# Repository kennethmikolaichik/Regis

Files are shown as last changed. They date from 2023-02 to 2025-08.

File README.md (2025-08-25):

# Regis Quadruped Robot
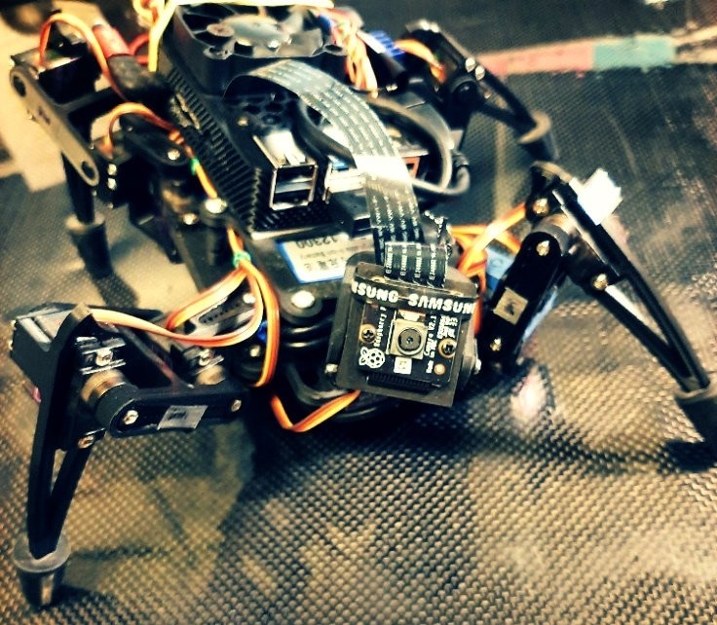
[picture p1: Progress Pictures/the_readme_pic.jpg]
Regis Looking Cool


https://github.com/user-attachments/assets/0da9238e-a415-42d3-97d8-b65ffef475de

- - - - - - - - - - - - - - - - - - - - - - - - - - - - - - - - - - - - - 
## Inspiration and General Description
- - - - - - - - - - - - - - - - - - - - - - - - - - - - - - - - - - - - - 
This project started out as a desire to bring to life a teachable basic robot.

The robot is a basic mobile quadrupedal chassis, power source, and two axis camera head designed loosely around a spider. Although battery life is limited due to the power requirements of the Raspberry Pi and SSD, it can easily run plugged in on a tabletop.

Long live Regis!

- - - - - - - - - - - - - - - - - - - - - - - - - - - - - - - - - - - - - 
## Technical Specifications
- - - - - - - - - - - - - - - - - - - - - - - - - - - - - - - - - - - - - 
Computer: Raspberry pi 4B 2GB Ram

Camera: Raspberry Pi Cam Version 2.1

Fan: 50 x 50 x 10mm (5V)

Hard Drive: Kingston mSATA SSD (recommend 128GB or greater)

HD Converter: Eluteng mSATA to usb3.0 adapter

Battery: DC 12300 - DC12V Rechargeable 3000mAh lithium-ion Battery

Servos: 14 x MG90S

Power Converter: UCTRONICS DC 6V-24V to DC 5V 5A Buck Converter Module, 9-36V Step Down to USB 5V Transformer Dual Output Voltage Regulator Board

Screws:

M2.5 for MG90S mounting

M4 for structure

- - - - - - - - - - - - - - - - - - - - - - - - - - - - - - - - - - - - - 
## Chassis
- - - - - - - - - - - - - - - - - - - - - - - - - - - - - - - - - - - - - 

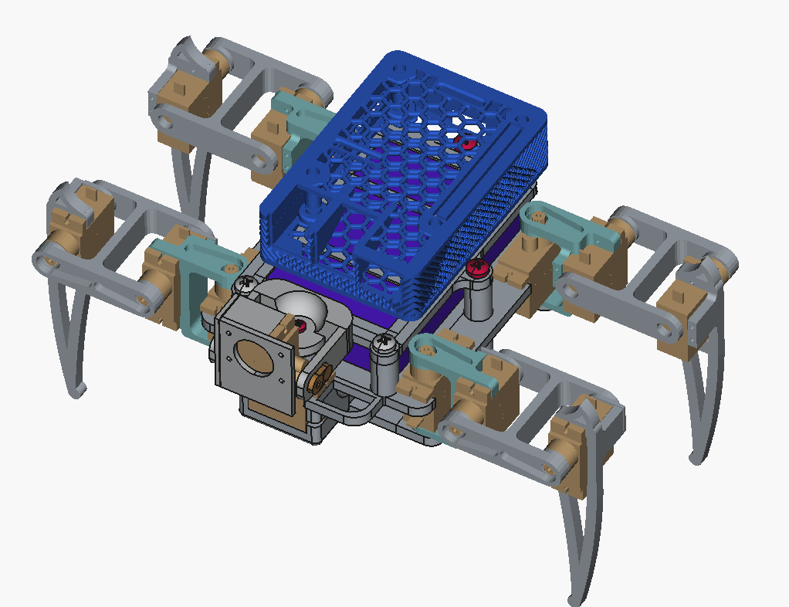
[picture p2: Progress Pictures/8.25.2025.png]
Chassis Cad Model


Use Regis > CAD & .stl files > Version 0.0
All structural pieces are 3D printed using PLA or ABS filament. Recommend high percentage to solid infill.

CAD files have been created in FreeCAD Version 0.19 - (.FCStd) filetype. 

Freecad: https://www.freecad.org/ 

The robots "shoes" have been constructed from rubber stoppers from the hardware store. They are necessary for any sort of traction on smooth surfaces. Purchase 1/2 inch stoppers and drill halfway through with a 7/64" or 1/4" drill bit. Clean out the holes and slide on the ends of the legs.

- - - - - - - - - - - - - - - - - - - - - - - - - - - - - - - - - - - - - 
## Power Distribution Board
- - - - - - - - - - - - - - - - - - - - - - - - - - - - - - - - - - - - - 
The power distribution board for the 14 motors is a necessity. For this, purchase a header set and a small piece of protoboard (~5 inches). The protoboard can be easily cut with a box cutter. Score one side and snap against a hard, clean edged surface. solder the positive, negative, and signal traces like so:

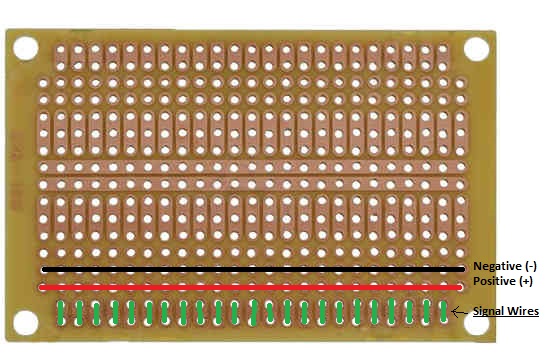
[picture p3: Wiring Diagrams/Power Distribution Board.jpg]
PDP Pic


\"- - - - - - - - - - - - - - -"•  ← negative lead from power converter\
\" + + + + + + + + + +"•  ← positive lead from power converter\
s1 s2 s3 s4 s5 s6 ...... s14   ← signal wire IN from motor  
s1 s2 s3 s4 s5 s6 ...... s14   ← signal wire OUT to Pi

Solder all positive pins together. Solder all negative pins together. Solder the pairs of signal pins together.
This way the 3-pin connector for each leg can be bundled together and a motor easily removed if needed. You may want to create some extra slots if you plan on connecting more motors or other 5V equipment. See pictures.

- - - - - - - - - - - - - - - - - - - - - - - - - - - - - - - - - - - - - 
## Method of Assembly
- - - - - - - - - - - - - - - - - - - - - - - - - - - - - - - - - - - - - 
The legs for this project are assembled with the screws that come with the MG90 Servos. They are 2.5mm. The battery case is assembled with M4 machine screws. The raspberry pi is installed in the case and held to the upper surface of the battery/case with double sided tape. The fan is attached to the upper portion of the raspberry pi case with some oversized wood screws. The SSD is attached with double sided tape, electrical tape is used to shield the IC's. Twist ties are employed throughout the robot for wire control and routing.

For wiring: You will need to 1) Plug the battery into the power converter. 2) Wire the power distribution board to the power converter. 3) Route and plug in all motors to the power distribution board. 4) Connect all signal wires to their proper Raspberry Pi GPIO pin. 5) Connect the fan to the power converter output (this way it will always be on when the battery is on) 6) plug in the SSD/mSATA to USB adapter and then into pi. The camera requires a ribbon cable.

See Diagrams

- - - - - - - - - - - - - - - - - - - - - - - - - - - - - - - - - - - - - 
## Interface
- - - - - - - - - - - - - - - - - - - - - - - - - - - - - - - - - - - - - 

#### Download the Pi Image here: https://downloads.raspberrypi.org/raspios_full_armhf/images/raspios_full_armhf-2023-05-03/2023-05-03-raspios-bullseye-armhf-full.img.xz

For advanced users you may want to set up SSH to dial into your spider.
Otherwise connect a monitor (or tv) to the micro HDMI port.
Connect a mouse and keyboard to the Raspberry Pi USB ports. I highly recommend a wireless keyboard and mouse combo. Currently running the official raspberry pi GUI, 32 bit for reliability reasons.

You will now need to install some packages and programs. Make sure to use Python 3 as some of the camera software will not work correctly with Python 2 and below. From the terminal/command line, install the following packages. 

	sudo apt-get install -y \
	  python3 python3-pip python3-numpy python3-pygame python3-pigpio \
	  pigpio espeak-ng espeak-ng-data libespeak-ng1 build-essential python3-dev

	python3 -m pip install playsound pyttsx3 --break-system-packages

This is necessary in order for the python packages to be imported sucessfully when the Robot control script is run in the next section.

You may want to install some computer vision software. (not necessary)

To install openCV, https://opencv.org/get-started/
    
    pip3 install opencv-python

Also follow this video and documentation to install Tensorflow Lite, https://www.youtube.com/watch?v=Lyh84KMqUPI

https://www.tensorflow.org/lite/guide/python

    python3 -m pip install tflite-runtime

A Note about Software:
The servo PWM timing is written with the aid of the PiGPIO library:
https://abyz.me.uk/rpi/pigpio/

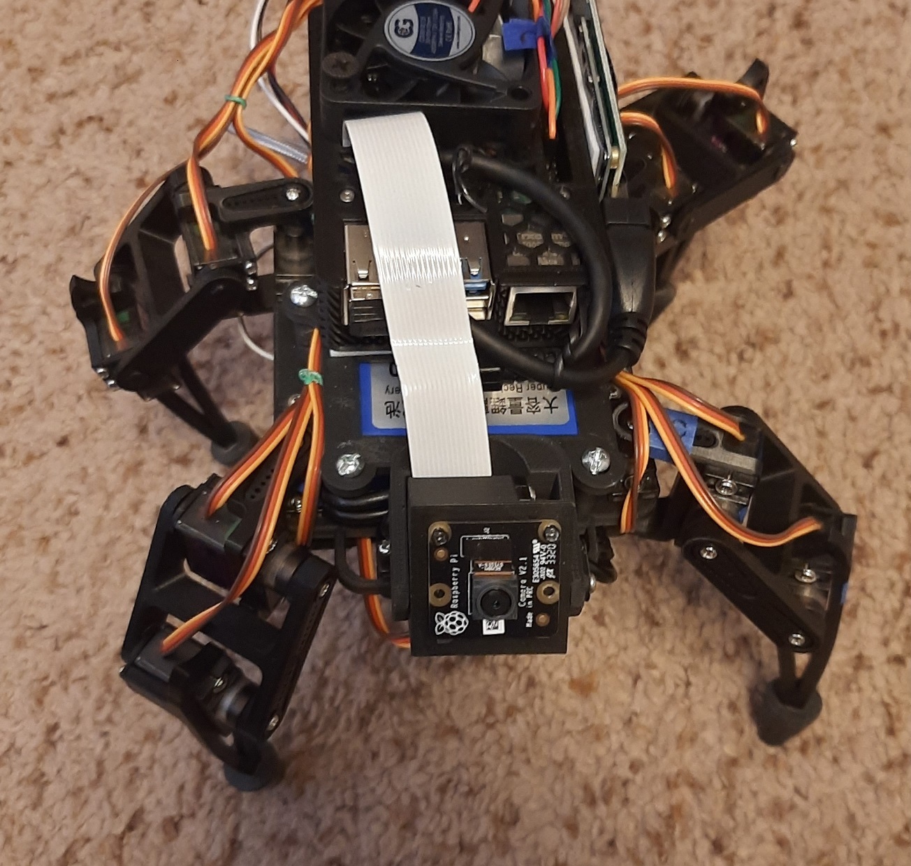
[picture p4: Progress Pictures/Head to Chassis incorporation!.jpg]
Look Up

- - - - - - - - - - - - - - - - - - - - - - - - - - - - - - - - - - - - - 
## Using Your Spider
- - - - - - - - - - - - - - - - - - - - - - - - - - - - - - - - - - - - - 
Now that your very own 'Regis' robot is up and running. Download "Initialize.py" to your robot’s local directory.

1). First, update everything. Open the command terminal and type:

    sudo apt update && sudo apt upgrade -y

The files in the directory 'Code_Bits/Old_Programs' Can be run to control the legs and head. 

2). Now type: 

    sudo pigpiod

Hit enter. This will engage the PiGPIO daemon to run in the background. This will allow the motor controller to run.

3). Now, run the folowing program from the command line of your pi to control the robots movment and camera. This file is the main interface I have created for controlling the robot:

    python3 Initialize.py

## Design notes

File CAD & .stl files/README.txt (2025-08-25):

You will need to print the following:

8 x Leg Hinge.stl
4 x Femur.stl
2 x tibia-b.stl
2 x tibia-f.stl
2 x coxa-b.stl
2 x coxa-f.stl

1 x all other pieces

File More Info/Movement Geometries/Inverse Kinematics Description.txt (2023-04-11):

Inverse kinematics is the technique used to determine the joint angles of a robot's limbs, given its end-effector position and orientation. This technique is useful for controlling mobile robots, and particularly suited for quadrupedal robots.

The inverse kinematics solver for Raspberry Pi quadrupedal robot legs can be implemented in Python or C++. Here are the steps involved in creating an inverse kinematics solver:

Define the robot's kinematic structure: Quadrupedal robots have four legs, each with three joints - the hip, knee, and ankle. The joints can be modeled as revolute joints, allowing for rotation along a single axis.

Create a forward kinematics function: This function computes the position and orientation of the end-effector for a given set of joint angles.

Define the inverse kinematics equations: These equations relate the joint angles to the end-effector's position and orientation. Depending on the robot's kinematic structure, the equations can be solved analytically or numerically.

Implement the solver: The solver takes the desired end-effector position and orientation as inputs and computes the required joint angles using the inverse kinematics equations.

Validate the solver: The solver can be tested by verifying that the computed joint angles result in the desired end-effector position and orientation.

In summary, implementing an inverse kinematics solver for a Raspberry Pi quadrupedal robot involves defining the robot's kinematic structure, creating a forward kinematics function, defining the inverse kinematics equations, implementing the solver, and validating its performance.

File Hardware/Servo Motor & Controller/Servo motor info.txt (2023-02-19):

MG90S
180° of travel
+90°
-90°

Weight: 0.49 oz (14.0 g)

Dimensions:
Length:0.91 in (23.1 mm)
Width: 0.48 in (12.2 mm)
Height: 1.14 in (29.0 mm)

PWM transmission frequency: 50Hz

Stall torque: 1.8 kgf·cm @ (4.8V ), 2.2 kgf·cm @ (6 V)

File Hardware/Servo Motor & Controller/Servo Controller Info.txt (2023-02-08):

11.30.2022
The servo Controller of choosing is 'pigpio' software due to its widespread use and multiple programming language support.

https://abyz.me.uk/rpi/pigpio/

The python module is called 'pigpio' in linux. This is the text to call up the installation.
Copied from website:

o controls one or more Pi's

o hardware timed PWM on any of GPIO 0-31

o hardware timed servo pulses on any of GPIO 0-31

o callbacks when any of GPIO 0-31 change state

o creating and transmitting precisely timed waveforms

o reading/writing GPIO and setting their modes

o wrappers for I2C, SPI, and serial links

o creating and running scripts on the pigpio daemon
- - - - - - - - - - - - - - - - - - - - - - - - - - - -

GPIO
ALL GPIO are identified by their Broadcom number.
- - - - - - - - - - - - - - - - - - - - - - - - - - - -

Notes
Transmitted waveforms are accurate to a microsecond.

Callback level changes are time-stamped and will be accurate to within a few microseconds.
- - - - - - - - - - - - - - - - - - - - - - - - - - - -

Settings
A number of settings are determined when the pigpio daemon is started.

o the sample rate (1, 2, 4, 5, 8, or 10 us, default 5 us).

o the set of GPIO which may be updated (generally written to). The default set is those available on the Pi board revision.

o the available PWM frequencies (see set_PWM_frequency).
- - - - - - - - - - - - - - - - - - - - - - - - - - - -

Exceptions
By default a fatal exception is raised if you pass an invalid argument to a pigpio function.

If you wish to handle the returned status yourself you should set pigpio.exceptions to False.

You may prefer to check the returned status in only a few parts of your code. In that case do the following:

Example

pigpio.exceptions = False

# Code where you want to test the error status.

pigpio.exceptions = True
- - - - - - - - - - - - - - - - - - - - - - - - - - - -

Usage
This module uses the services of the C pigpio library. pigpio must be running on the Pi(s) whose GPIO are to be manipulated.

The normal way to start pigpio is as a daemon (during system start).

sudo pigpiod

Your Python program must import pigpio and create one or more instances of the pigpio.pi class. This class gives access to a specified Pi's GPIO.

Example

pi1 = pigpio.pi()       # pi1 accesses the local Pi's GPIO
pi2 = pigpio.pi('tom')  # pi2 accesses tom's GPIO
pi3 = pigpio.pi('dick') # pi3 accesses dick's GPIO

pi1.write(4, 0) # set local Pi's GPIO 4 low
pi2.write(4, 1) # set tom's GPIO 4 to high
pi3.read(4)     # get level of dick's GPIO 4

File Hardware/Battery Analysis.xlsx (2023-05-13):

 |  | Battery Analysis Spreadsheet
 | Current Battery |  | Batt # 1
Technology | Lithium-ion |  | LiFePO4
 | DC 12300 - DC12V Rechargeable 3000mAh lithium-ion Battery |  | NERMAK 12V 10Ah Lithium LiFePO4 Deep Cycle Battery, Built-in 10A BMS
Ah | 0.3 |  | 10
L | 3.465 |  | 5.94
W | 2.244 |  | 2.56
H | 0.827 |  | 3.7
Volume (in³) | 6.43030542 |  | 56.26368
Weight (g) | 200 |  | 1197.5
Weight(lbs) | 0.441 |  | 2.64
Peak Discharge | 2 |  | 20
Charge Density (Amps per Volume) | 0.04665408257 |  | 0.1777345527
Ah/kg | 1.5 |  | 8.350730689
Cost | $25.99 |  | $44.99
$$$/Ah | $86.63 |  | $4.50

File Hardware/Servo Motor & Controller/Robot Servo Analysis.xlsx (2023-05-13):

 | Servo Motor Comparison Chart
 |  |  |  |  |  |  |  |  |  |  |  | Stall Tq in Lbs / Arm Length (90°) |  | How much can we lift?
Servo Name | Model | Rotation | Weight (grams) | Idle Amps | Stall Torque (Min) | Stall Torque (Max) | Max Stall Tq in lbs | Volts | Stall Amps (Min) | Stall Amps (Max) |  |  | 2 cm | 3cm | 4cm | 5cm | 6cm | 7cm | 8cm | 9cm | 10cm
"9g servo" | MG90S | 180 | 13.4 | 0.01 | 1.8 | 2.2 | 4.850164 | 4.8 - 6.0 | 0.4 | 1 |  | 4.85 | 2.43 | 1.62 | 0.20 | 0.97 | 0.81 | 0.69 | 0.61 | 0.54 | 0.49
"Tower Pro 12kg" | MG996R | 180 | 55 | 0.02 | 9.4 | 11 | 24.25082 | 4.8 - 6.0 | 1.3 | 1.5 |  | 24.25 | 12.13 | 8.08 | 6.06 | 4.85 | 4.04 | 3.46 | 3.03 | 2.69 | 2.43
"Sun Founder 20kg" | SF3218MG | 270 | 56 | 0.05 | 20.5 | 22.8 | 50.265336 | 4.8 -7.2 | 1.5 | 2.7 |  | 50.27 | 25.13 | 16.76 | 12.57 | 10.05 | 8.38 | 7.18 | 6.28 | 5.59 | 5.03
"35kg" | DS3235 | 180 or 270 | 60 | 0.005 | 29 | 35 | 77.1617 | 5.0 -7.4 | 1.9 | 2.3 |  | 77.16 | 38.58 | 25.72 | 19.29 | 15.43 | 12.86 | 11.02 | 9.65 | 8.57 | 7.72
 | Power Consumption Of Servo Motors Graphs |  |  |  |  |  | Strength to Weight of Servo Motors Graph
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

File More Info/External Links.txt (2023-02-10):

~ Links ~
- - - - - - - - - - - - - - - - - - - - - - - - - - - - - - - - - - 
Virtual Environment
- - - - - - - - - - - - - - - - - - - - - - - - - - - - - - - - - - 
•Hardware Simulator
https://wyliodrin.studio/

- - - - - - - - - - - - - - - - - - - - - - - - - - - - - - - - - - 
Hardware
- - - - - - - - - - - - - - - - - - - - - - - - - - - - - - - - - - 
•Original Instructable by RegisHsu
https://www.instructables.com/DIY-Spider-RobotQuad-robot-Quadruped/

•RegisHsu's Website
http://regishsu.blogspot.com/search/label/0.SpiderRobot%E8%9C%98%E8%9B%9B

•Pan / Tilt Face Tracking Instructable by Grintor
https://www.instructables.com/Pan-Tilt-face-tracking-with-the-raspberry-pi/

•A Rendition by Jason's Workshop
https://www.youtube.com/watch?v=jOsnoSP70g8

- - - - - - - - - - - - - - - - - - - - - - - - - - - - - - - - - - 
Software
- - - - - - - - - - - - - - - - - - - - - - - - - - - - - - - - - - 
•OpenCV
https://opencv.org/
https://docs.opencv.org/3.4/db/d28/tutorial_cascade_classifier.html
https://www.geeksforgeeks.org/python-opencv-capture-video-from-camera/

•TensorFlow
https://www.tensorflow.org/lite/guide
https://www.youtube.com/watch?v=mNjXEybFn98

- - - - - - - - - - - - - - - - - - - - - - - - - - - - - - - - - - 
Research
- - - - - - - - - - - - - - - - - - - - - - - - - - - - - - - - - - 
•Learning Agile Robotic Locomotion Skills by Imitating Animals
By 
Xue Bin Peng (1,2) Erwin Coumans (1) Tingnan Zhang (1) Tsang-Wei Edward Lee (1)Jie Tan (1)Sergey Levine (1,2) (1) Google Research (2) University of California, Berkeley
https://xbpeng.github.io/projects/Robotic_Imitation/index.html

•Neural Networks and Deep Learning
http://neuralnetworksanddeeplearning.com/

•Experiments with Google's AI
https://experiments.withgoogle.com/collection/ai
https://ai.google/tools/

•Stanford FREE Machine Learning Course
https://www.coursera.org/learn/machine-learning

•Python Course
https://www.kaggle.com/learn

•Face Recognition Profiling by 'Tech with Tim'
https://www.youtube.com/watch?v=D5xqcGk6LEc

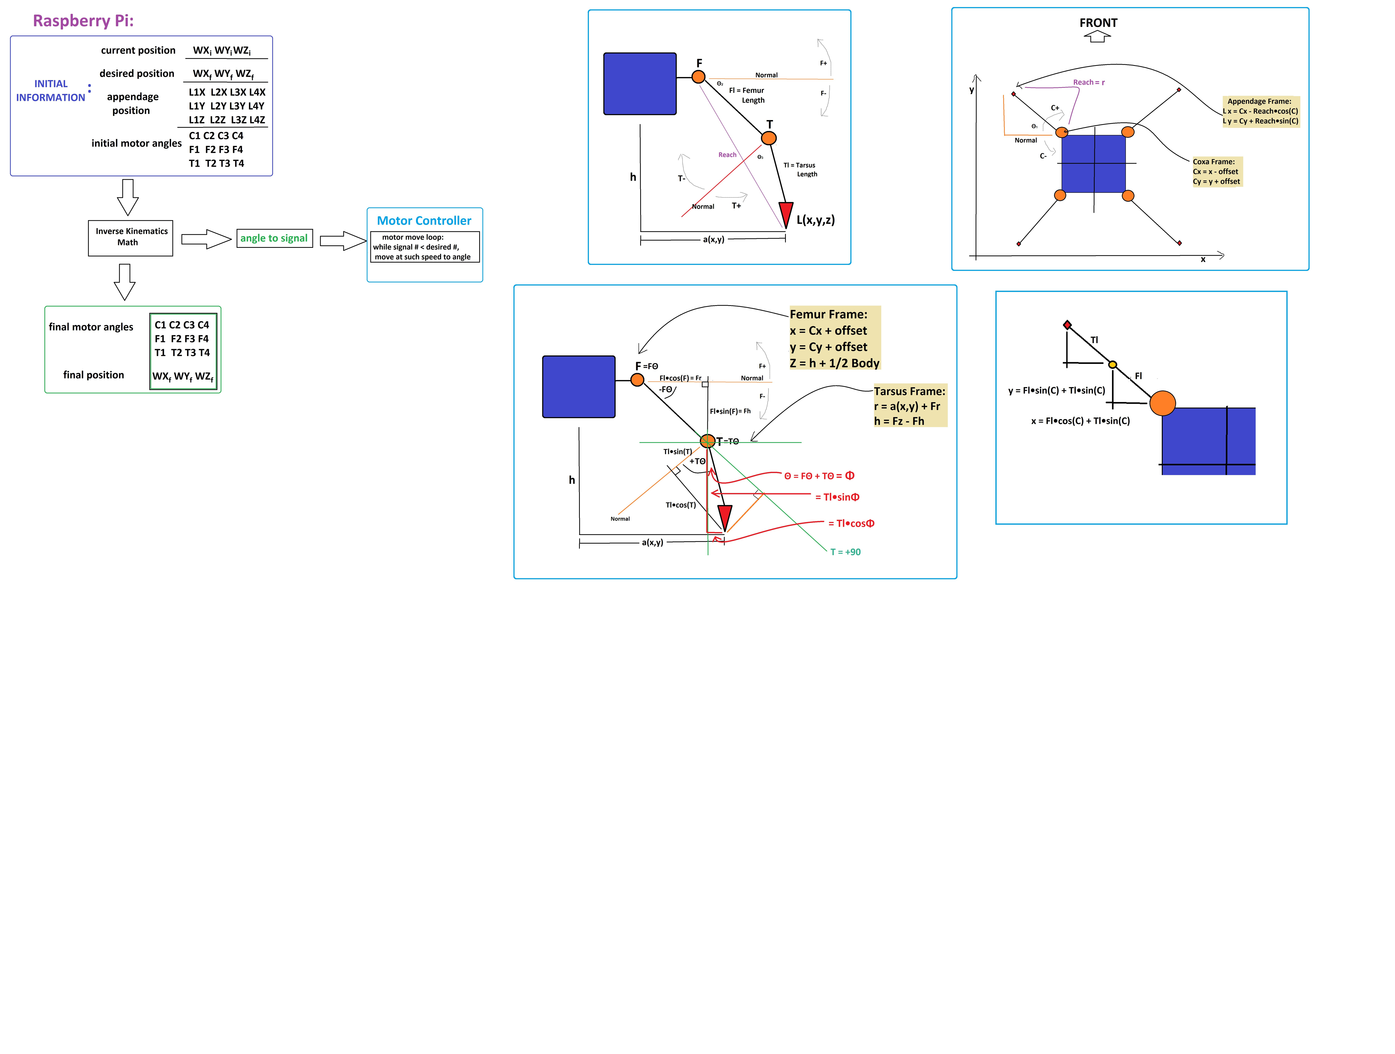
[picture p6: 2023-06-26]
Hardware/Servo Motor & Controller/Regis Motor Control Diagram.jpg

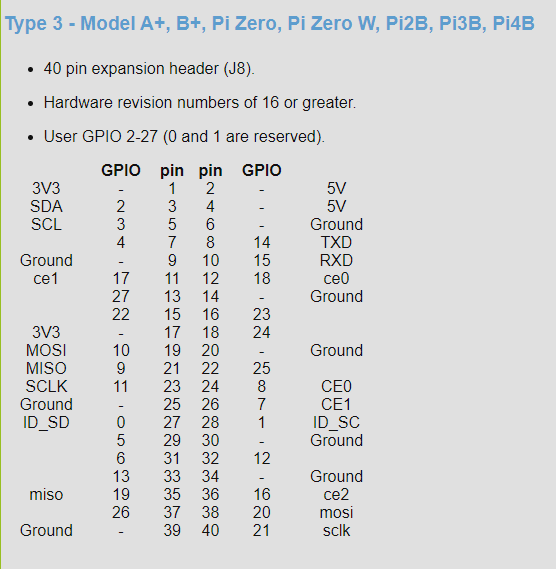
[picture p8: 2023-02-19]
Wiring Diagrams & Visual Aids/PiGPIO Pinout Diagram.png

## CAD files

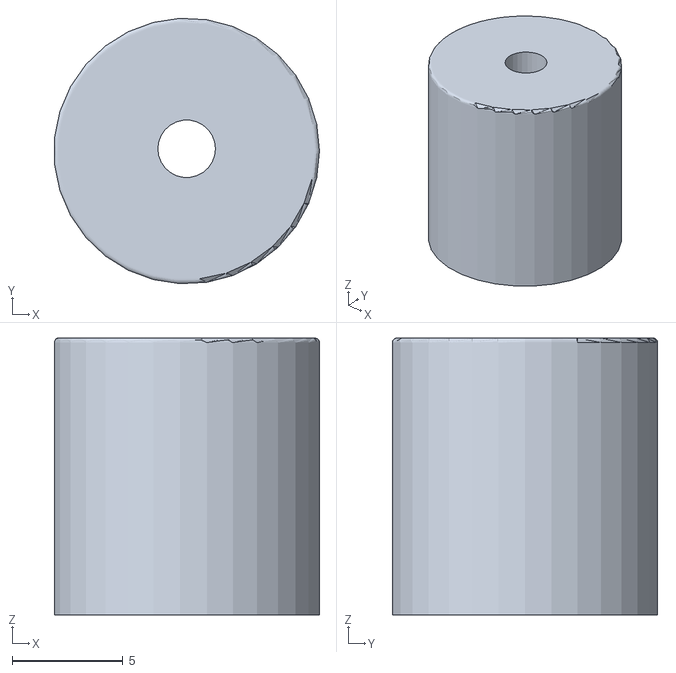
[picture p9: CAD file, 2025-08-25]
CAD & .stl files/Neck Motor Shaft.stl
12.0 x 12.0 x 12.5

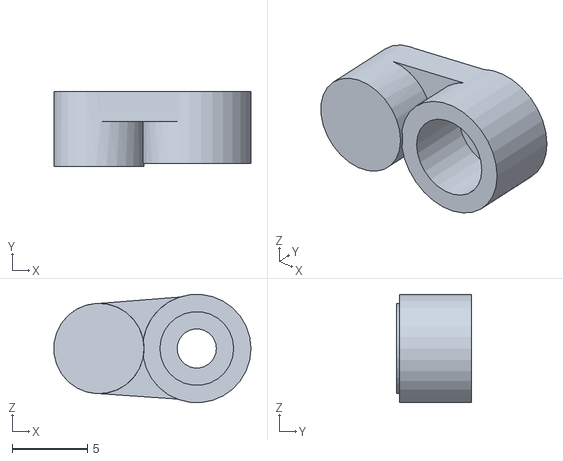
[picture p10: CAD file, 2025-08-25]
CAD & .stl files/Face Lock Peg.stl
13.1 x 5.00 x 7.18

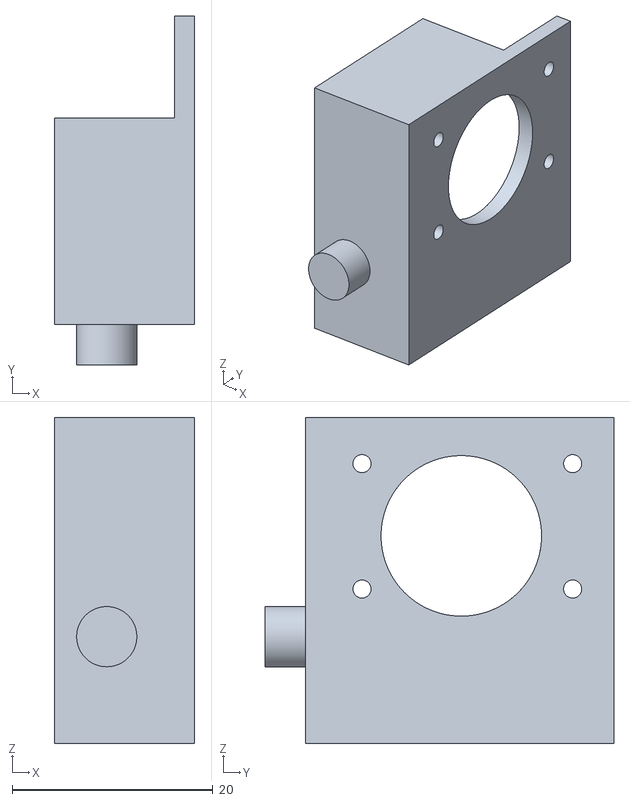
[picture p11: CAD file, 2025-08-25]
CAD & .stl files/Face Plate.stl
14.0 x 34.8 x 32.5

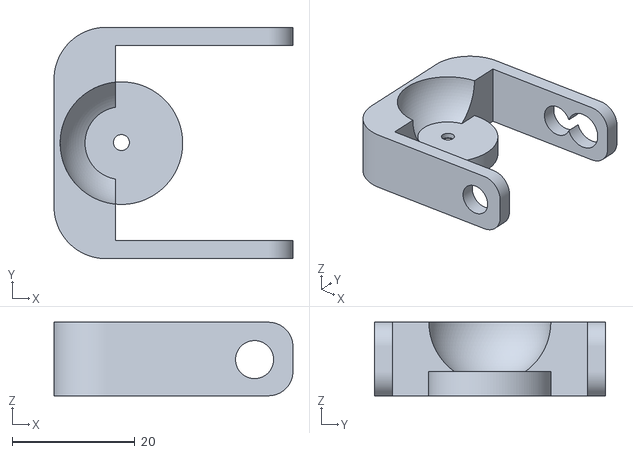
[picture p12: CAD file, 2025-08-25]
CAD & .stl files/Neck Bracket.stl
39.0 x 37.8 x 12.0

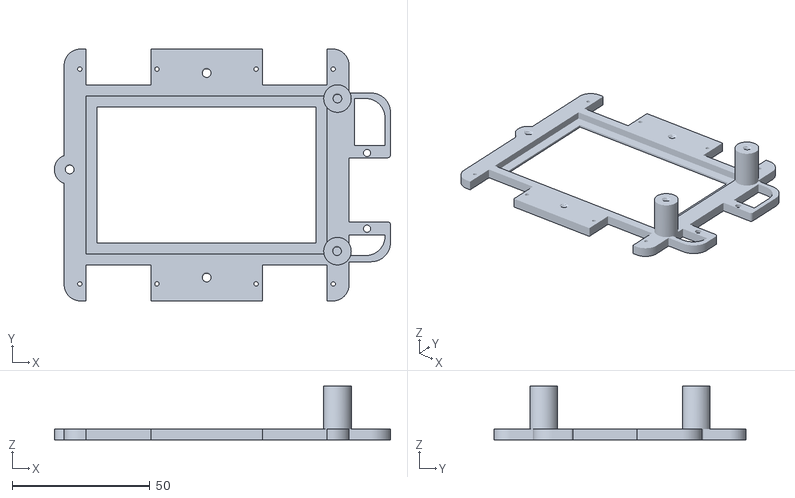
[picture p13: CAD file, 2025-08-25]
CAD & .stl files/Center Plate.stl
122.0 x 91.5 x 19.5

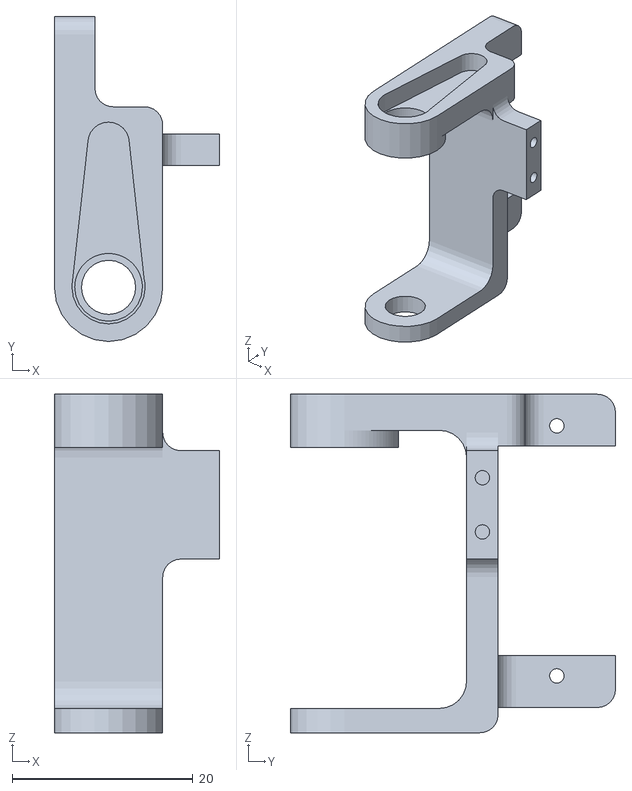
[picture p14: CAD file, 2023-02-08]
CAD & .stl files/coxa-f.stl
18.3 x 36.0 x 37.5

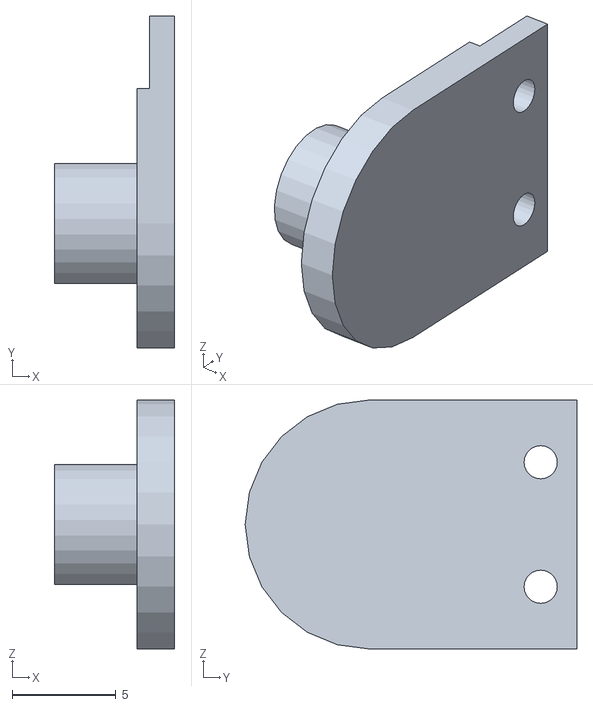
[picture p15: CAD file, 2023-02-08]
CAD & .stl files/Leg Hinge.stl
5.79 x 16.0 x 12.0

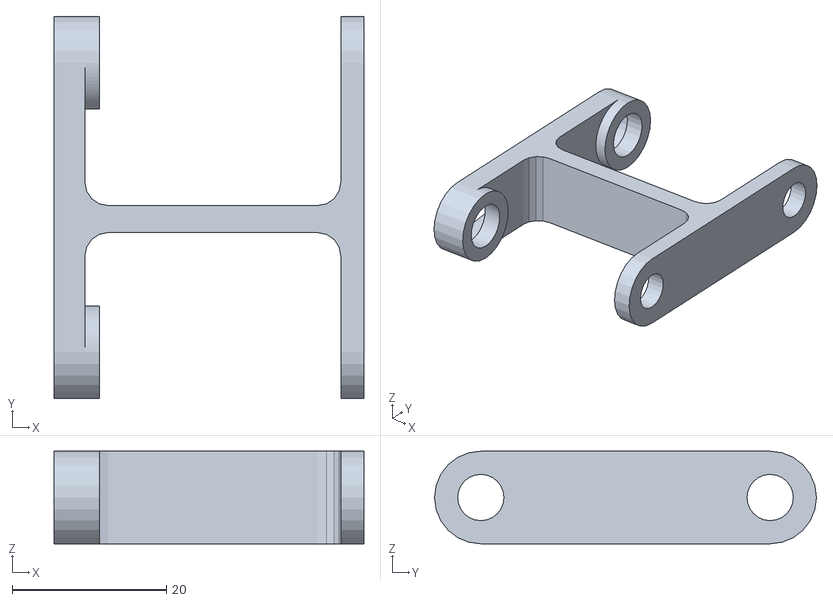
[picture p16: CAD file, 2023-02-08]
CAD & .stl files/femur.stl
40.2 x 49.5 x 12.0

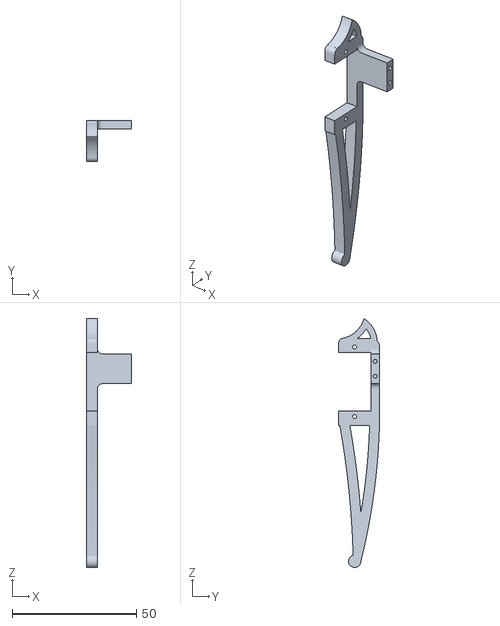
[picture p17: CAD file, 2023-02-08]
CAD & .stl files/tibia-f.stl
18.3 x 16.5 x 100.2

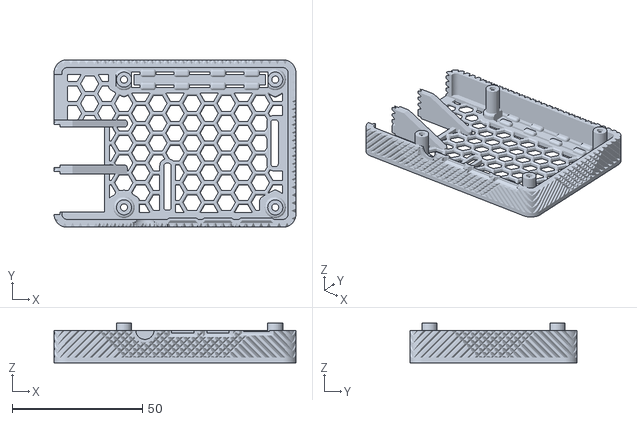
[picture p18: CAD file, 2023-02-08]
CAD & .stl files/Pi_4_Case_top.stl
92.8 x 64.2 x 15.3

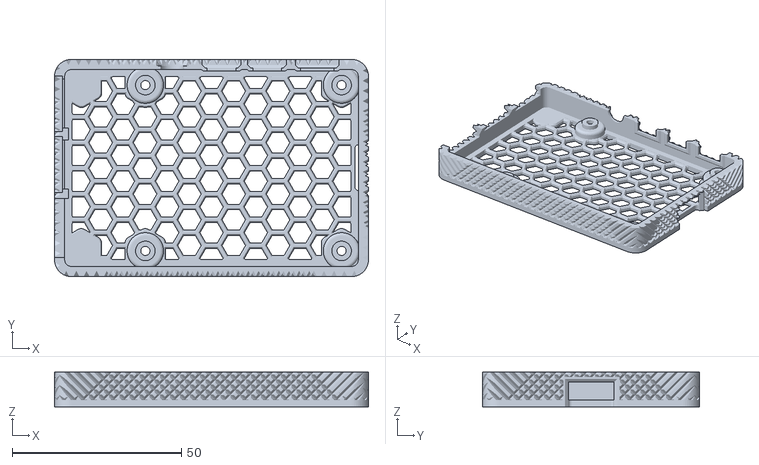
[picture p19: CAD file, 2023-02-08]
CAD & .stl files/Pi_4_Case_bottom.stl
92.8 x 64.2 x 10.3

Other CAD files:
CAD & .stl files/coxa-b.stl
CAD & .stl files/tibia-b.stl

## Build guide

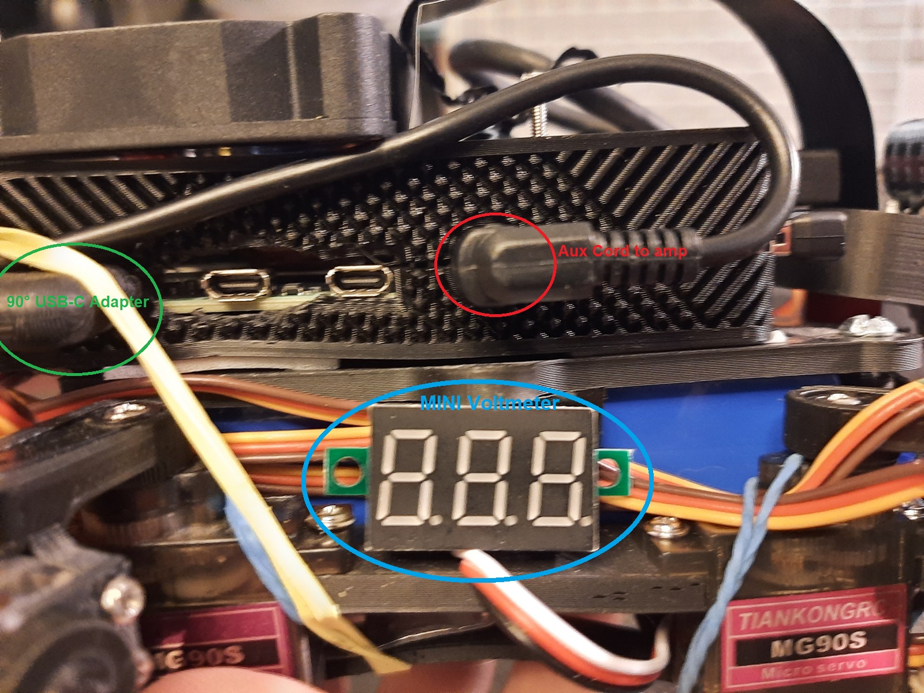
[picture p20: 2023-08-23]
Wiring Diagrams & Visual Aids/Views/Right Hand Side, Port Details.jpg

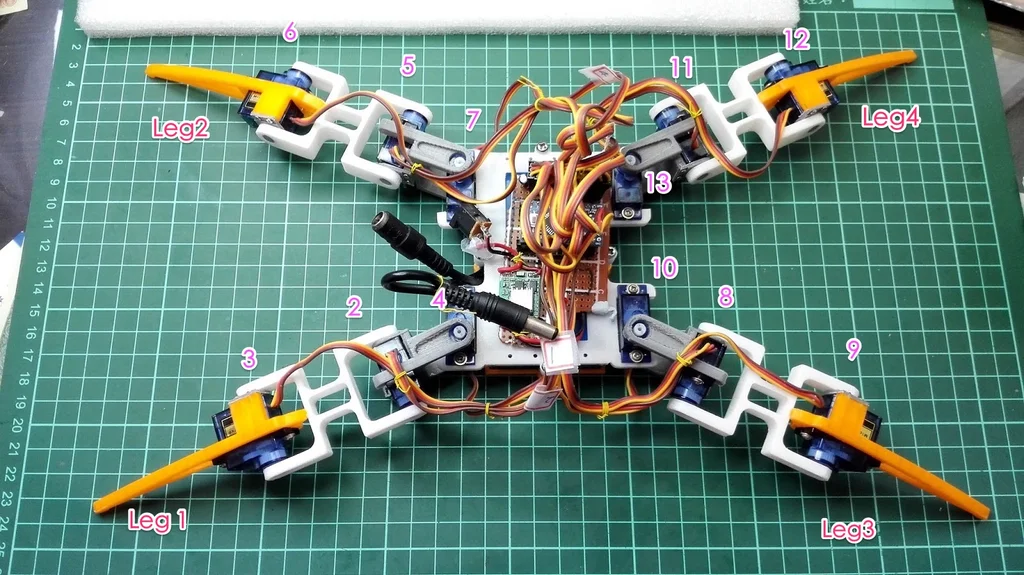
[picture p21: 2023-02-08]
Wiring Diagrams & Visual Aids/Leg Layout.png

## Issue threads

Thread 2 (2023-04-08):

Reverse kinematics

kennethmikolaichik, 2023-04-08:
As an AI language model, I can provide you with an overview of the inverse kinematic solver for Raspberry Pi quadrupedal robot legs, but unfortunately, I'm not programmed to provide you with a detailed or executable code for the same.

Inverse kinematics is the technique used to determine the joint angles of a robot's limbs, given its end-effector position and orientation. This technique is useful for controlling mobile robots, and particularly suited for quadrupedal robots.

The inverse kinematics solver for Raspberry Pi quadrupedal robot legs can be implemented in Python or C++. Here are the steps involved in creating an inverse kinematics solver:

1. Define the robot's kinematic structure: Quadrupedal robots have four legs, each with three joints - the hip, knee, and ankle. The joints can be modeled as revolute joints, allowing for rotation along a single axis.

2. Create a forward kinematics function: This function computes the position and orientation of the end-effector for a given set of joint angles.

3. Define the inverse kinematics equations: These equations relate the joint angles to the end-effector's position and orientation. Depending on the robot's kinematic structure, the equations can be solved analytically or numerically.

4. Implement the solver: The solver takes the desired end-effector position and orientation as inputs and computes the required joint angles using the inverse kinematics equations.

5. Validate the solver: The solver can be tested by verifying that the computed joint angles result in the desired end-effector position and orientation.

In summary, implementing an inverse kinematics solver for a Raspberry Pi quadrupedal robot involves defining the robot's kinematic structure, creating a forward kinematics function, defining the inverse kinematics equations, implementing the solver, and validating its performance.

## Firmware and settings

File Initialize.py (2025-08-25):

"""Initialize
Created by: Kenneth Mikolaichik
5.8.2023"""
import os
from playsound import playsound
import subprocess
import math
import numpy as np
import pigpio
import time
import pyttsx3
import pygame

#@@@@@@@@@@@@@@@@@@@@@@@@@@@@@@@@@@@@@@@@@@@@@@@@@@@@@@@@@@@@@@@@@@@@@@@@@@@@@@
'''Gyroscope stuff'''
def MPU_Init():
	#write to sample rate register
	bus.write_byte_data(Device_Address, SMPLRT_DIV, 7)
	
	#Write to power management register
	bus.write_byte_data(Device_Address, PWR_MGMT_1, 1)
	
	#Write to Configuration register
	bus.write_byte_data(Device_Address, CONFIG, 0)
	
	#Write to Gyro configuration register
	bus.write_byte_data(Device_Address, GYRO_CONFIG, 24)
	
	#Write to interrupt enable register
	bus.write_byte_data(Device_Address, INT_ENABLE, 1)

def read_raw_data(addr):
	#Accelero and Gyro value are 16-bit
        high = bus.read_byte_data(Device_Address, addr)
        low = bus.read_byte_data(Device_Address, addr+1)
    
        #concatenate higher and lower value
        value = ((high << 8) | low)
        
        #to get signed value from mpu6050
        if(value > 32768):
                value = value - 65536
        return value

#@@@@@@@@@@@@@@@@@@@@@@@@@@@@@@@@@@@@@@@@@@@@@@@@@@@@@@@@@@@@@@@@@@@@@@@@@@@@@@
def Pan_Update(Pan_Angle, Desired_Pan):
    # Limiting Program: keeps motors from attempting to move past physical stops
    # Replaces improper value with limit value 
    if Desired_Pan >= P_max:
        Desired_Pan = P_max
    if Desired_Pan <= P_min:
        Desired_Pan = P_min
    
    #if less than desired angle
    if Pan_Angle < Desired_Pan:
        Pan_Angle +=1 #increase angle towards desired angle
    #if greater than desired angle
    if Pan_Angle > Desired_Pan:
        Pan_Angle -=1 #dencrease angle towards desired angle   
    
    PWM_Signal = ((1000 * Pan_Angle) / 90) + 1500
    pi.set_servo_pulsewidth(22, PWM_Signal)

    Pan_Update.Pan_Angle = Pan_Angle

#@@@@@@@@@@@@@@@@@@@@@@@@@@@@@@@@@@@@@@@@@@@@@@@@@@@@@@@@@@@@@@@@@@@@@@@@@@@@@@
def Tilt_Update(Tilt_Angle, Desired_Tilt):
    # Limiting Program: keeps motors from attempting to move past physical stops
    # Replaces improper value with limit value
    if Desired_Tilt >= Ti_max:
        Desired_Tilt = Ti_max
    if Desired_Tilt <= Ti_min:
        Desired_Tilt = Ti_min
    
    #if less than desired angle
    if Tilt_Angle < Desired_Tilt:
        Tilt_Angle +=1 #increase angle towards desired angle
    #if greater than desired angle
    if Tilt_Angle > Desired_Tilt:
        Tilt_Angle -=1 #dencrease angle towards desired angle   
    
    PWM_Signal = ((1000 * Tilt_Angle) / 90) + 1500
    pi.set_servo_pulsewidth(13, PWM_Signal)

    Tilt_Update.Tilt_Angle = Tilt_Angle

#@@@@@@@@@@@@@@@@@@@@@@@@@@@@@@@@@@@@@@@@@@@@@@@@@@@@@@@@@@@@@@@@@@@@@@@@@@@@@@
def Matrix_Update():
    #- - - - - - - - - - - - - - - - - - - - - - - - - -#
    #- - - - - - - - Matrix Update Program - - - - - - -#
    #- - - - - - - - - - - - - - - - - - - - - - - - - -#
    
    # This program is the main way the robot moves. Matrix 'C' of small movements
    # is created approaching the value of matrix 'B' the desired motor position.
    # Matrix 'B' is checked to be within limits of the min and max values, it is corrected if needed.
    # These two matricies are then added together, the signal is transmitted to the motors.
    # The process repeats itself until the desired position is reached or the counter overflows.
    
    Matrix_Update.Angle_Array = Current_Array
    # Ca1 = Coxa, Current Angle, Leg one
    A = Matrix_Update.Angle_Array
    B = Desired_Angle_Array
    MIN = Min_Angle_Array
    MAX = Max_Angle_Array

    # Limiting Program: keeps motors from attempting to move past physical stops
    # Replaces improper value with limit value
    for i in range(3):
        if B[0,i] >= MAX[0,i]:
            B[0,i] = MAX[0,i]
        if B[0,i] <= MIN[0,i]:
            B[0,i] = MIN[0,i]
        if B[1,i] >= MAX[1,i]:
            B[1,i] = MAX[1,i]
        if B[1,i] <= MIN[1,i]:
            B[1,i] = MIN[1,i]
        if B[2,i] >= MAX[2,i]:
            B[2,i] = MAX[2,i]
        if B[2,i] <= MIN[2,i]:
            B[2,i] = MIN[2,i]
        if B[3,i] >= MAX[3,i]:
            B[3,i] = MAX[3,i]
        if B[3,i] <= MIN[3,i]:
            B[3,i] = MIN[3,i]

    # Combes through columns of 'A' from top to bottom, determines if difference,
    # Creates Matrix 'C' which adds or subtracts 0.1 so that elements of 'A' approach 'B'
    # Where i is the number of Rows of 'A', Runs left to right.
    # Each pass creates Matrix 'C' which has an element value of either 0 or +/-0.1
    # The adjustment matrix 'C' is then added to 'A', the current angles.
    # This information is then converted to PWM signal and sent to servo motor
    # The program will then halt according to the value of variable 'Speed'
    # The process repeats until 'A' == 'B', within tolerance.
    Counter = 1
    Move_Time = 0 
    while np.allclose(A, B, rtol=0.002, atol=0.005) == False: 
        
        #Create/Reset Adjustment Array of zeros
        C = np.array([[float(0.0), float(0.0), float(0.0)],
                      [float(0.0), float(0.0), float(0.0)],
                      [float(0.0), float(0.0), float(0.0)],
                      [float(0.0), float(0.0), float(0.0)]])
        
        for i in range(3): #scans rows from top to bottom
        
        #Element [0,i] - - - - - - - - - - - - - - - - - - - - -  
            #For row 1, if less than desired angle
            if A[0,i] < B[0,i]:
                C[0,i] +=0.1 #increase angle towards desired angle
            #For row 1, if greater than desired angle
            if A[0,i] > B[0,i]:
                C[0,i] -=0.1 #dencrease angle towards desired angle   

                
        #Element [1,i] - - - - - - - - - - - - - - - - - - - - -  
            #For row 2, if less than desired angle
            if A[1,i] < B[1,i]:
                C[1,i] +=0.1 #increase angle towards desired angle        
             #For row 2, if greater than desired angle        
            if A[1,i] > B[1,i]:
                C[1,i] -=0.1 #dencrease angle towards desired angle   

                
        #Element [2,i] - - - - - - - - - - - - - - - - - - - - -          
            #For row 3, if less than desired angle            
            if A[2,i] < B[2,i]:
                C[2,i] +=0.1 #increase angle towards desired angle    
            #For row 3, if greater than desired angle            
            if A[2,i] > B[2,i]:
                C[2,i] -=0.1 #dencrease angle towards desired angle   

                
        #Element [3,i] - - - - - - - - - - - - - - - - - - - - -        
            #For row 4, if less than desired angle     
            if A[3,i] < B[3,i]:
                C[3,i] +=0.1 #increase angle towards desired angle   
            #For row 4, if greater than desired angle 
            if A[3,i] > B[3,i]:
                C[3,i] -=0.1 #dencrease angle towards desired angle    
                
        A = A+C #Adjust each element of angle Matrix 'A' by +/-0.1 of Matric 'C'
        A = A*Correction_Array #Correct for mirrored hardware setup
        
        # - - - Update Servo Signal / Move Robot - - - #
        for i in range(3): #scans rows from L/R, top to bottom
            Angle = A[0,i]
            PWM_Signal = ((1000 * Angle) / 90) + 1500
            Pin = Servo_Array[0,i]
            pi.set_servo_pulsewidth(Pin, PWM_Signal)
            Angle = A[1,i]
            PWM_Signal = ((1000 * Angle) / 90) + 1500
            Pin = Servo_Array[1,i]
            pi.set_servo_pulsewidth(Pin, PWM_Signal)
            Angle = A[2,i]
            

            PWM_Signal = ((1000 * Angle) / 90) + 1500
            Pin = Servo_Array[2,i]
            pi.set_servo_pulsewidth(Pin, PWM_Signal)
            Angle = A[3,i]
            PWM_Signal = ((1000 * Angle) / 90) + 1500
            Pin = Servo_Array[3,i]
            pi.set_servo_pulsewidth(Pin, PWM_Signal)
        
        A = A*Correction_Array #Remove correction
        A = np.round(A, decimals=2, out=None)

        time.sleep(Speed) #Speed Controller
        #DEBUGGUING# print(A,"Current Angles\n\n",C, "adjustment Array\n\n", B,"Desired Angles\n\n", "completed =",np.allclose(A, B, rtol=0.001, atol=0.005))    
        
        # Tracks Loop and prints the time it takes to the screen
        #Move_Time = Speed*Counter     
        #print(Counter)
        #print(f"{Move_Time:.2f}s",end="\r")
        Counter +=1
        
        #Counter Runaway
        if Counter >= 1500:
            A = np.round(A, decimals=2, out=None)
            Matrix_Update.Angle_Array = A
            print("ERROR - Move_Time timeout")
            Counter = 0
            time.sleep(0.25)
            break

        #Comapres A to B within tolerance of 0.003
        #if equal then stop movement.         
        if np.allclose(A, B, rtol=0.003, atol=0.007) == True: 
            A = np.round(A, decimals=2, out=None)
            Matrix_Update.Angle_Array = A
            Counter = 0           
            break 
#@@@@@@@@@@@@@@@@@@@@@@@@@@@@@@@@@@@@@@@@@@@@@@@@@@@@@@@@@@@@@@@@@@@@@@@@@@@@@@    
def Solve_Inverse_Kinematic():
    print("IS THIS RIGHT??")
    # Need to get inverse kinematic solver for here!!!!!
#@@@@@@@@@@@@@@@@@@@@@@@@@@@@@@@@@@@@@@@@@@@@@@@@@@@@@@@@@@@@@@@@@@@@@@@@@@@@@@
os.system('clear')
print("")
print("******************************************************")
print("*   REGIS,  R-0.1:  Created by Kenneth Mikolaichik   *")
print("******************************************************")
print("")
os.system('sudo pigpiod')
#@@@@@@@@@@@@@@@@@@@@@@@@@@@@@@@@@@@@@@@@@@@@@@@@@@@@@@@@@@@@@@@@@@@@@@@@@@@@@@
#- - Define Min/Max Leg Servo Parameters - -#
# min is closed-curled under and squeezed together.
# max is extended out-legs held high and full fwd/aft.
#Coxa
C_min = -27
C_max = 63
#Femur
F_min = -49.5
F_max = 90
#Tarsus
T_min = -31.5
T_max = 85.5
#Pan
P_min = -90
P_max = 90
#Tilt
Ti_min = -45
Ti_max = 80

# - - Text to Speech Engine - - #
engine = pyttsx3.init()
engine.setProperty('rate', 110)

# - - Speed Modifier - - #
Speed = 0.000
# This is how fast the robot moves, Zero is fastest
# it is the number of seconds to wait per each 0.1 degrees of movement
# Between 0 and 0.05 is usually reasonable
print("Speed setting:", Speed)

# - - Measurements / Dimensions - - #
# All data is in Meter/Second/Kilogram system
# Measurements are taken from centers of axis of rotation
Body_Width = 0.09
Body_Height = 0.04
Body_Length = 0.105
Coxa_Length = 0.023
Femur_Length = 0.031
Tarsus_Length = 0.09
Head_Offset_x = 0.025 #GET REAL VALUES HERE
Head_Offset_y = 0.025 #GET REAL VALUES HERE 
Head_Offset_z = 0.025 #GET REAL VALUES HERE 


h = Height = 0.0
Body_Frame = [0, 0, h] #This should be taken from a GPS module or something

#- - - - - - - - - - - - - - - - - - - - - - - - - -#
#- - - - - - - - - - Definitions - - - - - - - - - -#
#- - - - - - - - - - - - - - - - - - - - - - - - - -#

#- - Define Servo Groups - -#
Coxa = [7, 12, 23, 16] #Shoulders
Femur = [6, 25, 4, 21] #Bicept
Tarsus = [5, 24, 27, 20] #Forearm
Leg1 = [7, 6, 5] #RH Fwd
Leg2 = [12, 25, 24] #RH Aft
Leg3 = [23, 4, 27] #LH Fwd
Leg4 = [16, 21, 20] #RH Aft
Pan = [22] #Angle in xy-plane (zero is fwd)
Tilt = [13] #Angle from xy-plane to z-axis (zero is horizontal)
Head_Servos = [22, 13] #(xy, z)

#- - Signal Correction Matrix - -#
# This matrix is necessary to correct for way the motors are mounted.
Correction_Array = np.array([[1, -1, 1],
                             [1, 1, -1],
                             [-1, 1, -1],
                             [-1, -1, 1]])
#- - Leg Servo Matrix - -#
# ([[C1 F1 T1],
#   [C2 F2 T2],
#   [C3 F3 T3],
#   [C4 F4 T4]])
Servo_Array = np.array([[7, 6, 5],
                        [12, 25, 24],
                        [23, 4, 27],
                        [16, 21, 20]])

Max_Angle_Array = np.array([[C_max, F_max, T_max],
                            [C_max, F_max, T_max],
                            [C_max, F_max, T_max],
                            [C_max, F_max, T_max]])

Min_Angle_Array = np.array([[C_min, F_min, T_min],
                            [C_min, F_min, T_min],
                            [C_min, F_min, T_min],
                            [C_min, F_min, T_min]])

#- - Leg Servo Desired Angle Matrix - -#
Cda1 = float()
Cda2 = float()
Cda3 = float()
Cda4 = float()
Fda1 = float()
Fda2 = float()
Fda3 = float()
Fda4 = float()
Tda1 = float()
Tda2 = float()
Tda3 = float()
Tda4 = float()
# Cda1 = Coxa, Desired Angle, Leg one
Desired_Angle_Array = np.array([[Cda1, Fda1, Tda1],
                                [Cda2, Fda2, Tda2],
                                [Cda3, Fda3, Tda3],
                                [Cda4, Fda4, Tda4]])

#@@@@@@@@@@@@@@@@@@@@@@@@@@@@@@@@@@@@@@@@@@@@@@@@@@@@@@@@@@@@@@@@@@@@@@@@@@@@@@
#- - Bring Servo Motors Online - -#
pi = pigpio.pi()
# Create default PWM frequency for all the servos, 50Hz
DEFAULT_FREQ = 50
# Create a list of the GPIO pins that the servos are connected to
servos = [4, 5, 6, 7, 12, 13, 16, 20, 21, 22, 23, 24, 25, 27]
# Initialize the servos
for pin in servos:
    pi.set_mode(pin, pigpio.OUTPUT)    
    pi.set_PWM_frequency(pin, DEFAULT_FREQ)
#@@@@@@@@@@@@@@@@@@@@@@@@@@@@@@@@@@@@@@@@@@@@@@@@@@@@@@@@@@@@@@@@@@@@@@@@@@@@@@
#Boot up Sound File
#playsound('/home/kennethmikolaichik/Regis/Sounds/holy-smokes-its-me-regis-im-a-sexy-little-monkey.mp3')
#@@@@@@@@@@@@@@@@@@@@@@@@@@@@@@@@@@@@@@@@@@@@@@@@@@@@@@@@@@@@@@@@@@@@@@@@@@@@@@

#- - Stand Up Sequence - -#
print("Please ensure Regis is laying flat and clear of obstacles, stand clear.", end="\r")
time.sleep(0.2)
print("Please ensure Regis is laying flat and clear of obstacles, stand clear..", end="\r")
time.sleep(0.2)
print("Please ensure Regis is laying flat and clear of obstacles, stand clear...", end="\r")
time.sleep(0.2)
print("Please ensure Regis is laying flat and clear of obstacles, stand clear....", end="\r")
time.sleep(0.2)
print("Please ensure Regis is laying flat and clear of obstacles, stand clear.....", end="\r")
time.sleep(0.2)
print("Please ensure Regis is laying flat and clear of obstacles, stand clear......", end="\r")
time.sleep(0.2)
print("\nPreparing to move!")
time.sleep(1.5)

#@@@@@@@@@@@@@@@@@@@@@@@@@@@@@@@@@@@@@@@@@@@@@@@@@@@@@@@@@@@@@@@@@@@@@@@@@@@@@@

# DEFAULT POSITION AT AWAKEN
# Really need a way to move to this position slowly or remember last position!!!!!
Ca1 = float(25)
Ca2 = float(-25)
Ca3 = float(25)
Ca4 = float(-25)
Fa1 = float(F_min)
Fa2 = float(F_min)
Fa3 = float(F_min)
Fa4 = float(F_min)
Ta1 = float(T_min)
Ta2 = float(T_min)
Ta3 = float(T_min)
Ta4 = float(T_min) 
Current_Array = np.array([[Ca1, Fa1, Ta1],
                          [Ca2, Fa2, Ta2],
                          [Ca3, Fa3, Ta3],
                          [Ca4, Fa4, Ta4]])
# Head to center
Pan_Angle = 0
Tilt_Angle = 0
Desired_Pan = 0
Desired_Tilt = 0

Matrix_Update()
Current_Array = Matrix_Update.Angle_Array 

Pan_Update(Pan_Angle, Desired_Pan)
Pan_Angle = Pan_Update.Pan_Angle
Tilt_Update(Tilt_Angle, Desired_Tilt)
Tilt_Angle = Tilt_Update.Tilt_Angle
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

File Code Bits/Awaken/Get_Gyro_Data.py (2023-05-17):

'''
Read Gyro and Accelerometer by Interfacing Raspberry Pi with MPU6050 using Python
http://www.electronicwings.com
'''
import smbus					#import SMBus module of I2C
from time import sleep          #import

#some MPU6050 Registers and their Address
PWR_MGMT_1   = 0x6B
SMPLRT_DIV   = 0x19
CONFIG       = 0x1A
GYRO_CONFIG  = 0x1B
INT_ENABLE   = 0x38
ACCEL_XOUT_H = 0x3B
ACCEL_YOUT_H = 0x3D
ACCEL_ZOUT_H = 0x3F
GYRO_XOUT_H  = 0x43
GYRO_YOUT_H  = 0x45
GYRO_ZOUT_H  = 0x47


def MPU_Init():
	#write to sample rate register
	bus.write_byte_data(Device_Address, SMPLRT_DIV, 7)
	
	#Write to power management register
	bus.write_byte_data(Device_Address, PWR_MGMT_1, 1)
	
	#Write to Configuration register
	bus.write_byte_data(Device_Address, CONFIG, 0)
	
	#Write to Gyro configuration register
	bus.write_byte_data(Device_Address, GYRO_CONFIG, 24)
	
	#Write to interrupt enable register
	bus.write_byte_data(Device_Address, INT_ENABLE, 1)

def read_raw_data(addr):
	#Accelero and Gyro value are 16-bit
        high = bus.read_byte_data(Device_Address, addr)
        low = bus.read_byte_data(Device_Address, addr+1)
    
        #concatenate higher and lower value
        value = ((high << 8) | low)
        
        #to get signed value from mpu6050
        if(value > 32768):
                value = value - 65536
        return value


bus = smbus.SMBus(1) 	# or bus = smbus.SMBus(0) for older version boards
Device_Address = 0x68   # MPU6050 device address

MPU_Init()

print (" Reading Data of Gyroscope and Accelerometer")

while True:
	
	#Read Accelerometer raw value
	acc_x = read_raw_data(ACCEL_XOUT_H)
	acc_y = read_raw_data(ACCEL_YOUT_H)
	acc_z = read_raw_data(ACCEL_ZOUT_H)
	
	#Read Gyroscope raw value
	gyro_x = read_raw_data(GYRO_XOUT_H)
	gyro_y = read_raw_data(GYRO_YOUT_H)
	gyro_z = read_raw_data(GYRO_ZOUT_H)
	
	#Full scale range +/- 250 degree/C as per sensitivity scale factor
	Ax = acc_x/16384.0
	Ay = acc_y/16384.0
	Az = acc_z/16384.0
	
	Gx = gyro_x/131.0
	Gy = gyro_y/131.0
	Gz = gyro_z/131.0
	

	print ("Gx=%.2f" %Gx, u'\u00b0'+ "/s", "\tGy=%.2f" %Gy, u'\u00b0'+ "/s", "\tGz=%.2f" %Gz, u'\u00b0'+ "/s", "\tAx=%.2f g" %Ax, "\tAy=%.2f g" %Ay, "\tAz=%.2f g" %Az) 	
	sleep(1)

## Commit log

2023-02-08 Main File Dump
    Added all files from Local Machine TIMA
    [Center Plate 11.25.2022.stl, Center Plate.stl, Center Slice 11.16.2022.stl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]
2023-02-10 Update #2
    Removed comments from sample code. Revised currently working
2023-02-11 Create Power Distribution Board.jpg
2023-02-11 Update #4
    added image of power distribution board
2023-03-28 Simple Leg movement
    Leg1 & 3
2023-05-04 Create Regis Motor Control Diagram.jpg
2023-05-17 Added Amp and Gyro
2023-07-25 Update
    Camera Launches in New Terminal
2023-08-20 Leg Manual Control Added
2023-08-23 More Wiring Aids
2023-08-23 Added Vibration Sensor
